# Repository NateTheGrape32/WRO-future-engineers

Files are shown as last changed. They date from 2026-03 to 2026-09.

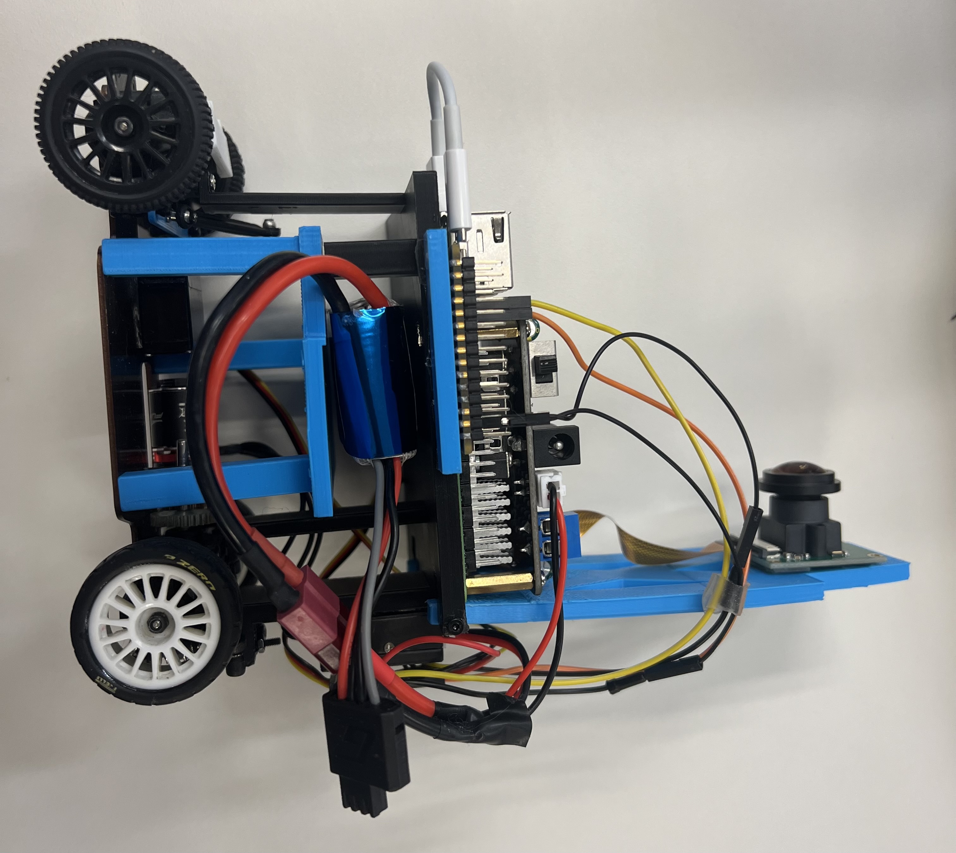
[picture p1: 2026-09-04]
CarPhoto/IMG_4004.jpeg

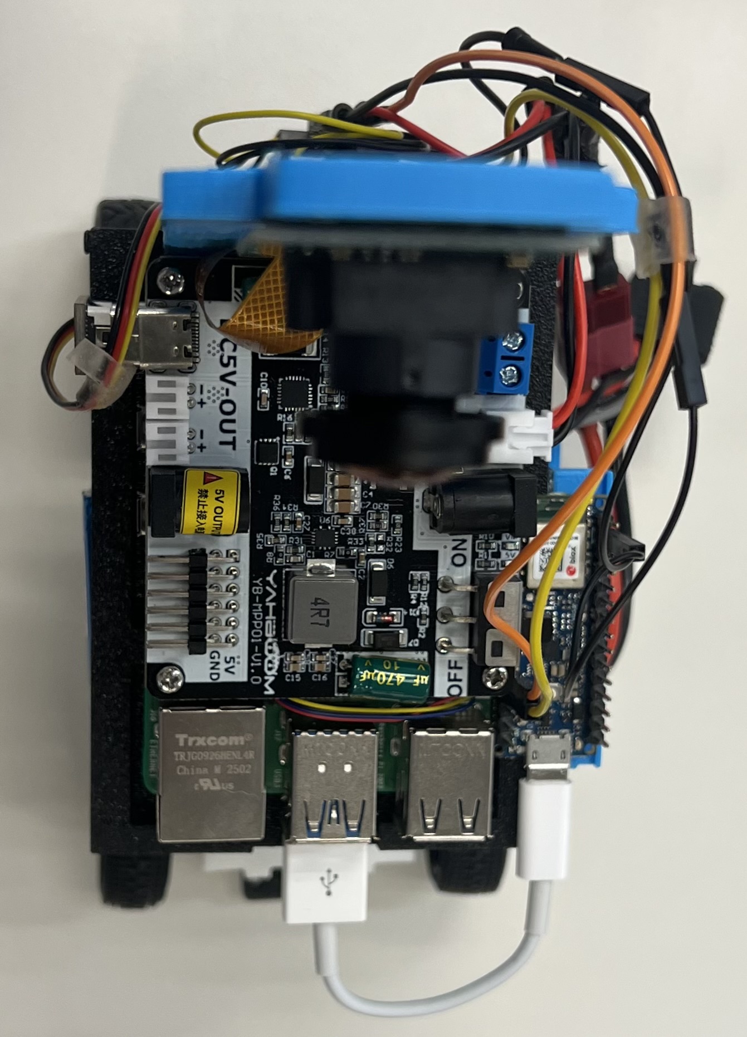
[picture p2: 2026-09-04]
CarPhoto/IMG_4001.jpeg

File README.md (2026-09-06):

# WRO-future-engineers
WRO 2026 Andrew and Nathan

YouTube Video: 
* [Open Challenge](https://youtu.be/nm6dfaRhhao) 
* [Obstacle Challenge](https://youtu.be/E2D7EVUFy_I)
## Nathan


## Andrew


# Materials
Originally we planned to use the following RC car for its chassis: [Original Chassis](https://www.amazon.ca/Full-Scale-Rear-Wheel-Rechargeable-Control-Crawler/dp/B0G24MWNGD?th=1)

However, this did not have the things that we wanted so we switched chassis to this one: [New Chassis](https://www.aliexpress.com/item/1005007171270606.html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)

In addition, we used this 2D LiDAR: [2D Lidar](https://www.aliexpress.com/item/1005003012681021.html?spm=a2g0o.order_list.order_list_main.31.67dd18029q37Y0)

This Pi camera: [Pi Camera](https://www.aliexpress.com/item/1005009258177201.htmlpdp_npi=6%40dis%21USD%21%2430.99%21%2415.19%21%21%21%21%21%402101e83017699792506122817ed50e%2112000048516190389%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) 

This Pi Power Regulator: [Power Regulator](https://ca.robotshop.com/products/yahboom-power-supply-expansion-board-raspberry-pi-5) 

This Battery/Power Supply: https://genstattu.com/gens-ace-1300mah-2s-7-4v-45c-g-tech-lipo-battery-pack-with-deans-plug/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 

This Arduino Nano: [Arduino Nano](https://store-usa.arduino.cc/products/nano-33-ble-sense-rev2) 

This Button: [Button](https://www.amazon.ca/dp/B01J9KO7DC?ref=ppx_yo2ov_dt_b_fed_asin_title&th=1)

Servo motor for driving: [Servo Motor](https://hitecrcd.com/hs-5055mg-economy-metal-gear-feather-servo/) 

# Mobility & Mechanical Design
In creating the chassis, we needed to incorporate these things which was done by:
- low center of gravity to maintain balance and reach higher speeds
    - creating a compact design as close to the ground as possible
    - Only light elements at the very top of the robot(camera)
- front wheel steering to have simple control over robot movement
    - choosing a chassis with Ackerman steering
    - controlling it with a servo motor
- differential gears
    - choosing a chassis with 2WD & differential gears
    - controlling it with a DC motor
- decent steering angle
    - Choosing a chassis that enabled an angle range of 65°–95°, center 80°
    - Programming our code to allow these angles through use of servo motor

Speed choice: MOTOR_DRIVE = 1600 µs
Through use of testing, we concluded that this is the fastest speed in which we could consistently obtain the same results, navigating safely through the challenge. 1500 is its stationary position.

# Gif
azhn33

# Wiring Diagram(file also included above)


# Power and Sensor Architecture
The Battery powers the Raspberry Pi, which is the master controller, through the Raspberry Pi's power regulator. The Raspberry Pi receives information from the Pi Camera. The Raspberry Pi then sends basic commands to the Arduino Nano which sends the information through the ESC into the servo and DC motors, which controls the steering and speed of the robot. 

Battery -> Power Regulator -> Raspberry Pi -> Arduino Nano -> ESC -> Servo & DC Motors

In choosing our sensor, we decided upon the the Pi camera because we deemed it would work well with the Raspberry Pi and had all the necessary functions such as a wide camera view and colour differentiation enabling it to see both the walls and pillars

# Software Architecture & Obstacle Strategy
## Open Challenge
For the Open Challenge, we have 2 modes; TURNING MODE and FOLLOW_WALL MODE. 
### FOLLOW_WALL MODE
During the wall following mode, the robot uses a combination of PD control and the Pi cameras input of the amount of the walls within its view in order to calculate how close to each wall the robot is, adjusting the robot as it goes. It automatically knows that the the bigger wall is closer and should move towards the smaller of the 2. To achieve this, we had 2 ROI(regions of intrest) on each side of the camera in which the camera would detect the amount of black, Thus knowing the ratio of the distance to each. In using this ratio, we could calculate what needed to be done in order to get to the middle. Originally, we set the kp(present error) = 0.5 & kd(predicted future error) = 0.1 but after further testing, we concluded that the robot didn't adjust quickly enough so with testing, we concluded that the perfect numbers were kp = 0.7 & kd = 0.3. 
### TURNING MODE
On the other hand, TURNING MODE is used once one of the walls disappears completely. Once this is the case, we know that the robot has reached a point where there is no wall on one side and so the robot starts turning for a few seconds or until the wall is visible again on the side where it previously wasn't. This allows us to preform the sharper turns without having to increase the kp & kd values to ones that may have the robot overcorrect. 

## Obstacle Challenge
Meanwhile, for the Obstacle Challenge, the Pi camera notifies the pi of the closest pilar, whether red or green. When the pi receives this information, it shifts over to one side of the track by increasing the amount of wall the camera should be seeing on one side compared to the other. 

## Lap Counting
Meanwhile, the robot also counts the laps using the blue and orange lines. after having counted 23 blue and orange lines, the robot enters a time of "STOP_DELAY" in order to stop not at the line located in the corner of the map but at the intended side of the map. 
In the end, all of the motor commands are sent to the Arduino Nano as simple commands, only stating whether it is a command to the servo motor or the DC motor and what degree/speed it should be set to. 

# Systems Thinking & Engineering Decisions

## Arduino ↔ Raspberry Pi Split

We divided the robot's jobs between the Arduino and Raspberry Pi based on what each device is good at:
- Arduino: Handles the IMU and controls the motors using PWM.
- Raspberry Pi: Handles the camera and computer vision using OpenCV.

The Arduino is better for tasks that need very accurate timing. The Raspberry Pi runs Linux, which can interrupt programs, so it cannot guarantee the precise microsecond timing needed for reliable PWM control. On the other hand, the Arduino does not have enough processing power or the software environment needed to run OpenCV effectively.

This split lets each device focus on the job it is best suited for.

## IMU Drift Mitigation

Gyroscopes can slowly become inaccurate over time because of small measurement errors, known as gyro drift.

To reduce this, the robot calibrates the gyro at startup by taking 2,000 samples over about 6 seconds while the robot is not moving. This gives us an estimate of the gyro's normal error, which can then be removed from later measurements.

We also use a dead-zone where values with abs(z) < 0.1 are treated as zero. This stops very small amounts of sensor noise from being interpreted as real movement.

The tradeoff is that extremely small rotations might be ignored. However, this is acceptable because we care more about reliably detecting larger turns than detecting tiny movements.

## Color Space Choices

We use different color spaces for different vision tasks.

- LAB: Used for detecting walls. It handles changes in brightness better, making wall detection more reliable under different lighting.
- HSV: Used for detecting colored pillars and lines. It makes it easier to isolate specific colors based on their hue.

Using different color spaces is a tradeoff: instead of using one method for everything, we chose the method that works best for each type of object.

## Iteration and Improvements

The robot was improved through repeated testing and changes shown in the commit history.

Some important improvements included:
- kp and kd tuning: Adjusted the PID controller to make the robot steer more smoothly and accurately.
- Reduced ROI height: Focused vision processing on the most useful part of the image.
- Added IMU turn confirmation: Used the IMU to help confirm that a turn actually happened instead of relying only on the camera.
- Added pillar detection: Improved the robot's ability to recognize important objects in its environment.

These changes show an implement → test → improve process. Instead of designing everything perfectly from the start, we used testing and observed problems to guide improvements.

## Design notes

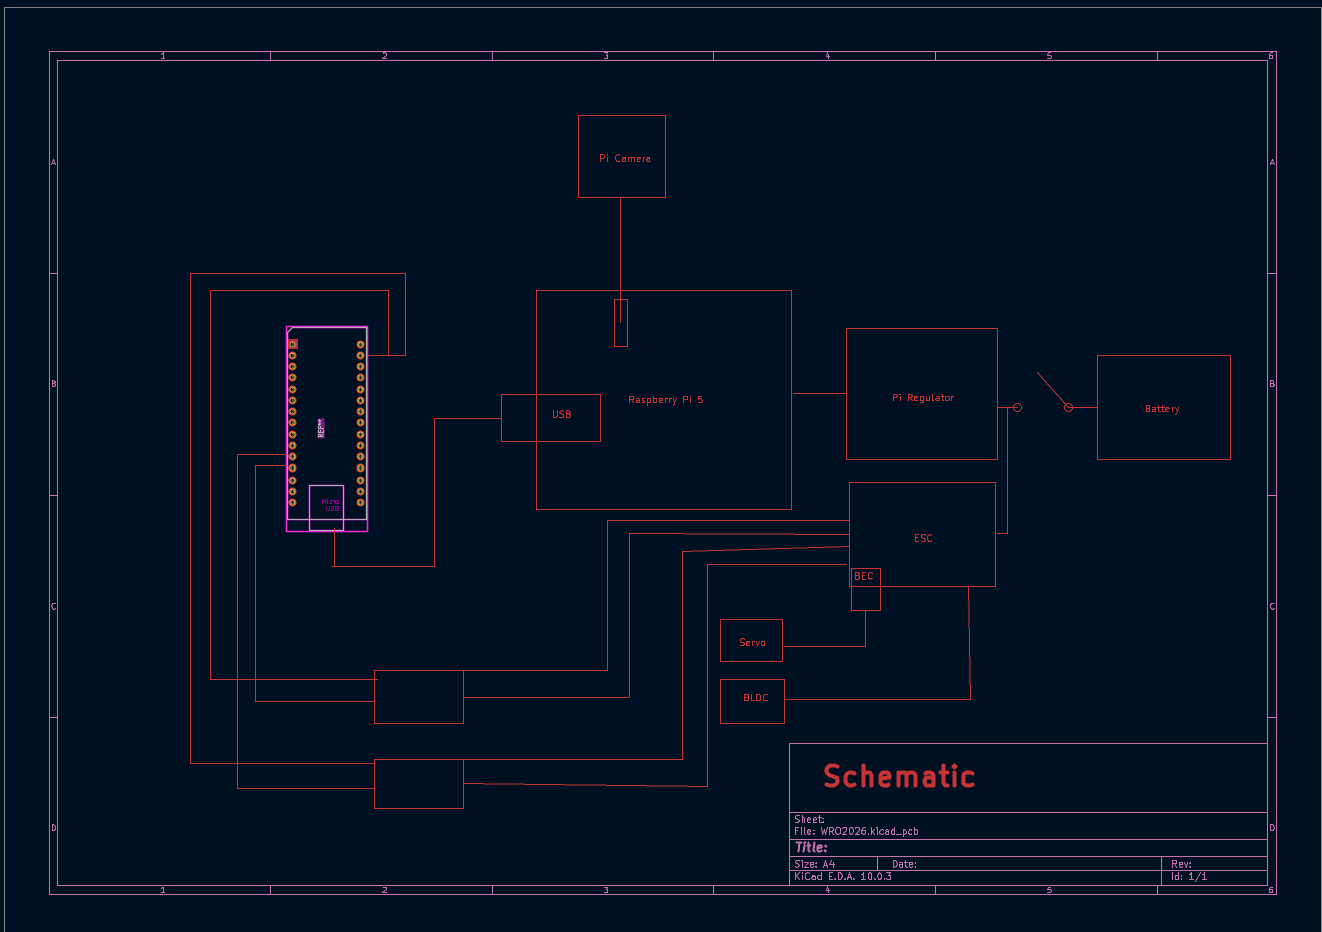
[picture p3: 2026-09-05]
Schematic.png

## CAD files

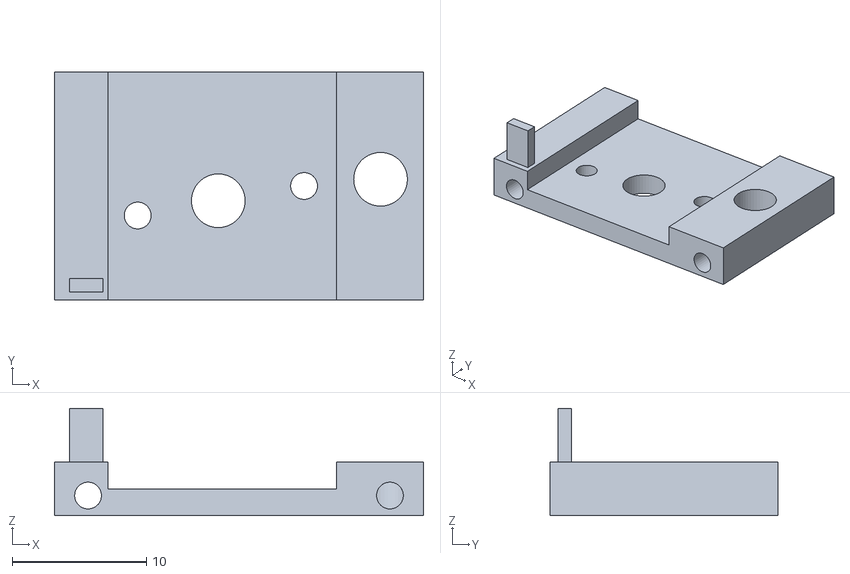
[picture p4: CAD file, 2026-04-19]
3D Designs/GearHolder2.stl
27.5 x 17.0 x 8.00

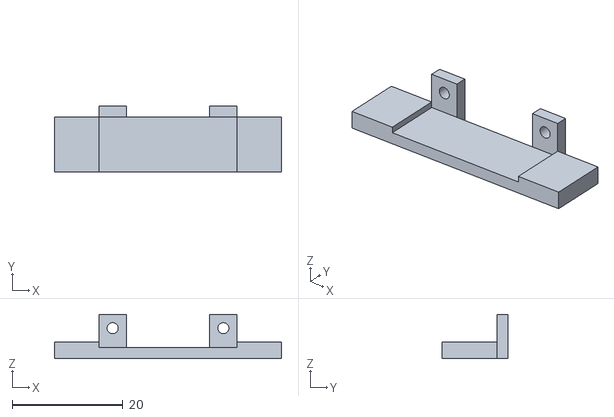
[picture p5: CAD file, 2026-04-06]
3D Designs/Wheel holder2.stl
41.0 x 12.0 x 8.00

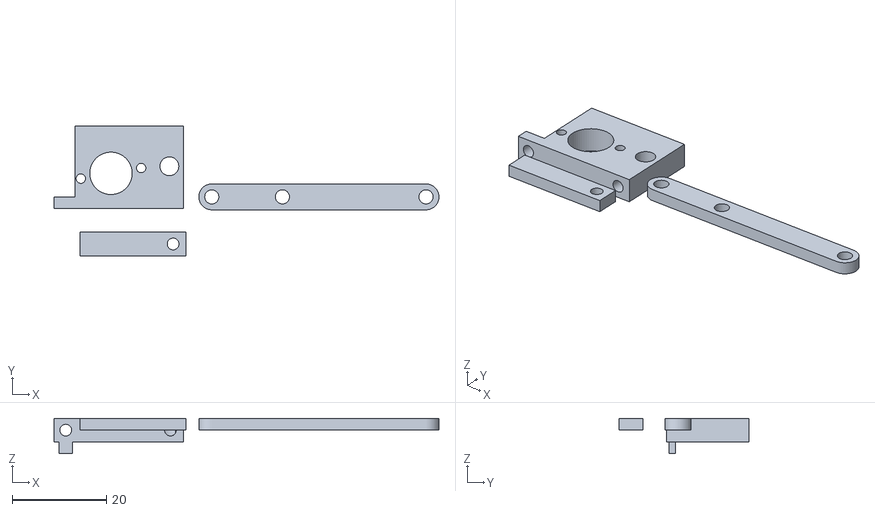
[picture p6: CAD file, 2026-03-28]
3D Designs/Bottom Parts.stl
81.8 x 27.5 x 7.50

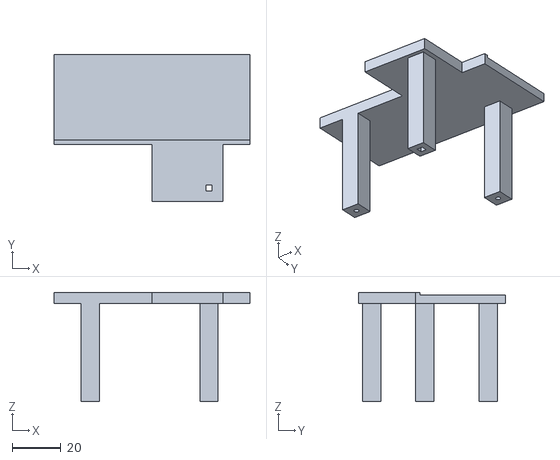
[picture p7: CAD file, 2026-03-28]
3D Designs/Battery & Arduino.stl
80.0 x 60.0 x 44.5

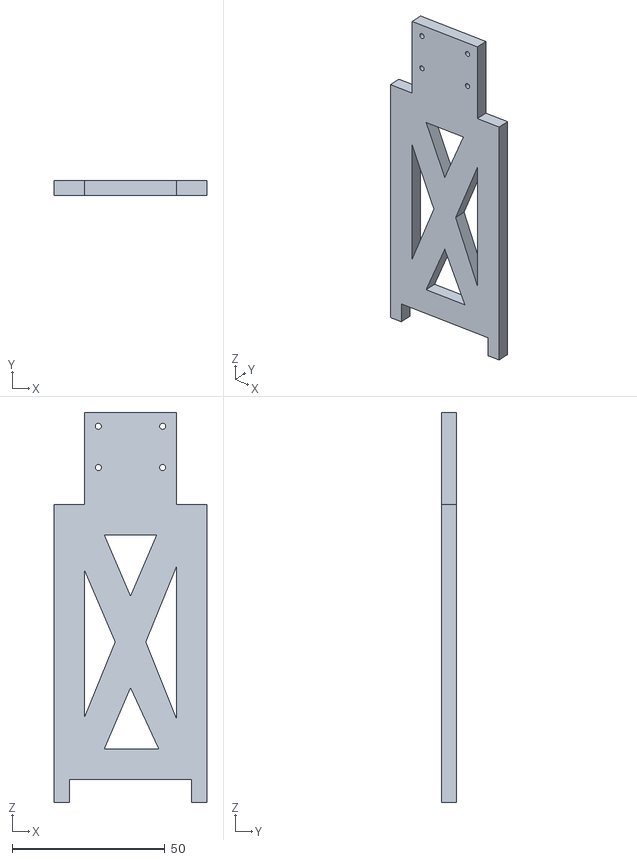
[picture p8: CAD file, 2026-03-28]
3D Designs/Camera.stl
50.0 x 5.00 x 127.5

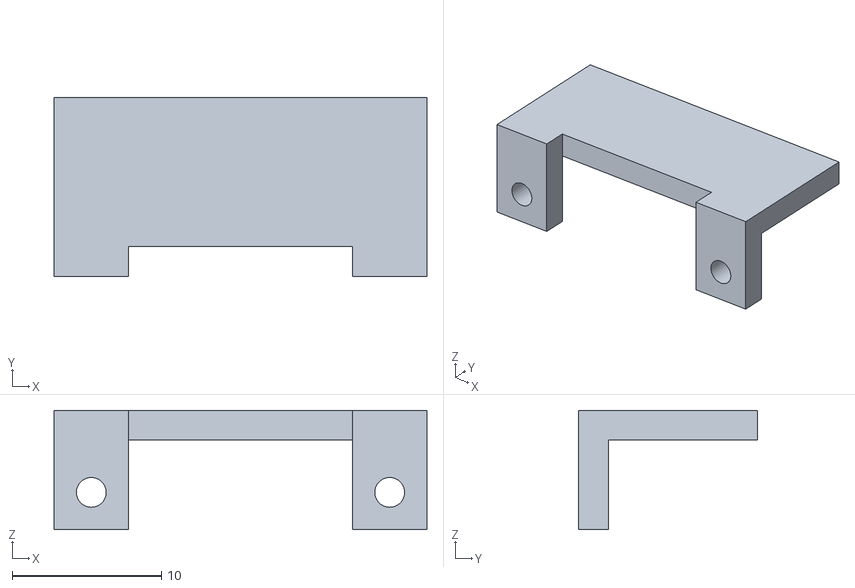
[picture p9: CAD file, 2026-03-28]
3D Designs/Wheel holder.stl
25.0 x 12.0 x 8.00

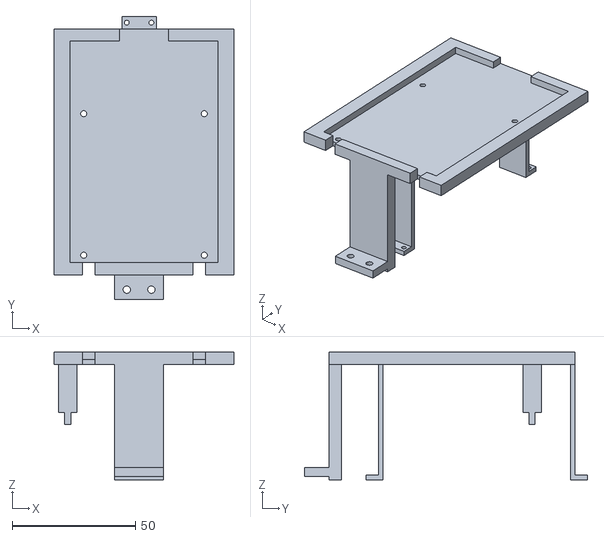
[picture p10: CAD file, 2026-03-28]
3D Designs/raspberryPi.stl
73.0 x 115.0 x 52.0

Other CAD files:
3D Designs/GearHolder.stl

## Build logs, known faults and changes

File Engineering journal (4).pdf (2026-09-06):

Engineering Journal

WRO Autonomous Driving Challenge

Team Name: Potato Nadoes
Country: Canada
Competition Year: 2026
Team Members: Nathan Li and Andrew Deng

YouTube Video(Open Challenge): https://youtu.be/nm6dfaRhhao

YouTube Video(Obstacle Challenge): https://youtu.be/E2D7EVUFy_I

Abstract

Our team developed an autonomous vehicle designed to sense walls and obstacles, adjusting to them. Throughout the project, we followed an iterative engineering process: we identified problems, developed solutions, tested them, analyzed the results, and redesigned the system where necessary. Our final vehicle combines servo motor Ackerman steering, DC motor 2WD with differential gears, Pi camera, and raspberry pi
5. Our proudest engineering achievement was [specific achievement], because it required us to solve [specific technical challenge] through multiple rounds of testing and refinement.
1. The Challenge & Our Systems Strategy

1.1 Understanding the Challenge

Before building the vehicle, we broke the overall autonomous-driving problem into smaller engineering systems:

Mechanical system – chassis, wheels, steering, drivetrain

Power system – battery, voltage regulation, motor power

Sensing system – cameras, encoders, IMU, 2D Lidar

Computing system – onboard computer and microcontrollers

Software system – perception, decision-making, control

Testing system – repeatable experiments, measurements, and performance evaluation

This decomposition allowed us to develop and test individual subsystems before integrating the complete vehicle.

1.2 Constraints

During development, we identified several important constraints:

Constraint | Why it matters | Example engineering impact
Vehicle size: 300 × 200 × 300 mm max | Limits chassis and
| component placement | We had to make the sensor
| | mounts compact.
Vehicle weight: 1.5 kg max Affects acceleration,
| traction, and motor load | We used lighter materials to leave
| | weight for electronics.
4 wheels required | Limits drivetrain
| architecture | We couldn't use a differential-drive
| | layout.
One steering actuator | Limits steering design We needed a mechanically
| | synchronized steering system.
Maximum 2 driving motors Limits available driving
| power | Motor selection and gearing
| | became important.
No omnidirectional/ball
wheels | Limits wheel selection We needed conventional wheels
| | with a suitable steering geometry.
Fully autonomous operationNo human intervention
| during the run | Software needed reliable recovery
| | and decision-making.
No RF/Bluetooth/Wi-Fi during competition | Prevents wireless
| control/communication | Debugging and inter-controller
| | communication had to be wired or
| | disabled.
Sensors are unrestricted | Gives freedom but
| creates integration
| challenges | We had to balance sensor
| | capability against weight, space,
| | processing, and power.

Battery choice is

unrestricted | Lots of design freedom | We still had to balance capacity,
| | weight, voltage, and current
| | capability.
Only wired communication between electromechanical components | Limits communication
| architecture | We had to carefully plan wiring
| | and connectors.

Fixed vehicle size during
the run
| Prevents expanding
| mechanisms from
| simplifying parking | Our final dimensions had to work
| | for both driving and parking.
2. Mechanical Iteration & Mobility

2.1 Chassis Evolution

Rather than designing the final chassis immediately, we developed several versions.

Version 1: Chassis bought from amazon (Feb 22 2026)

Problem: The chassis that we purchased off amazon was not very modification friendly, very difficult to tear apart and did not have differential gears or a usable steering system

Test Result: We were unable to put our servo and DC motors to use and designing 3D prints was very difficult.

Lesson: This taught us that we can't truly be sure of what we're purchasing online as it may seem usable before we actually receive it.

Change for Version 2: We switched to a simple chassis with only the required things such as differential gears and a steering system. (March 1 2026)

Figure 1 – Version 1 prototype(gear system)

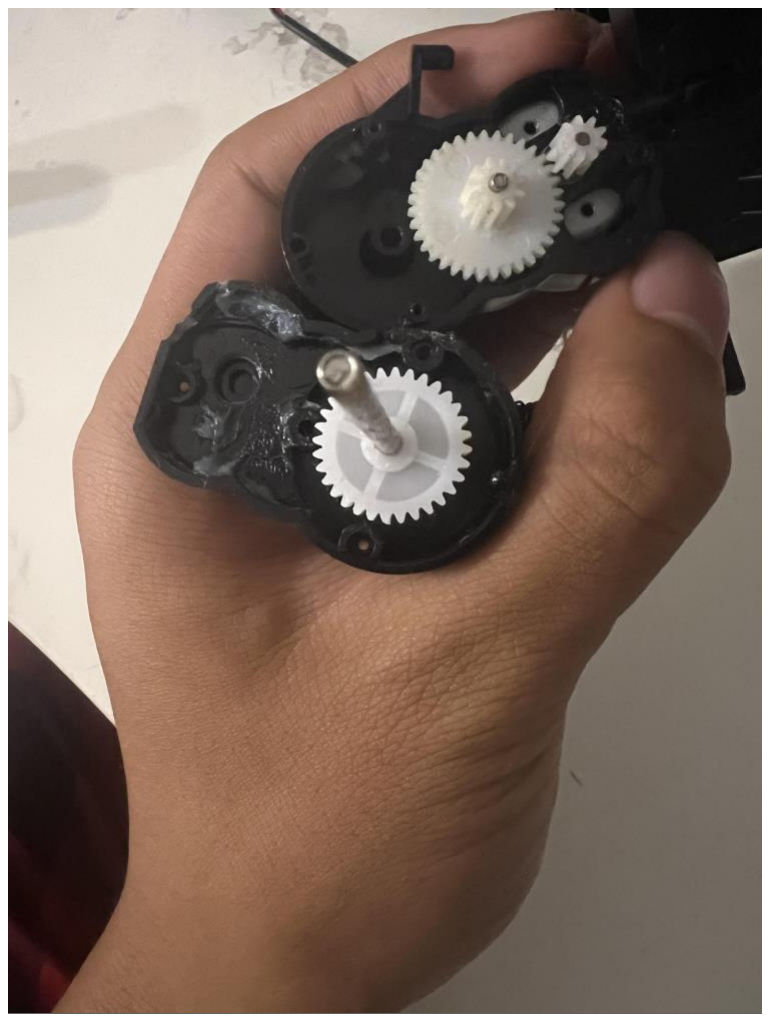
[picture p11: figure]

Version 3:

Problem identified from Version 2: The chassis had nothing to hold down the wheels

Modification: We added a wheel holder over to keep the wheels down using a 3D print

Test Result: It worked for a while but then broke, and we had to create new ones.

Lesson: We learned to always have spare parts in case the 3D prints broke.

Change for Version 3: Gear holder created

Version 3 – Final Design(March 22 2026)

The final chassis incorporated differential gears and a working steering system, completing everything we needed for the competition. These changes were based on the results of previous physical tests rather than solely on assumptions.

Figure 3 – Final chassis

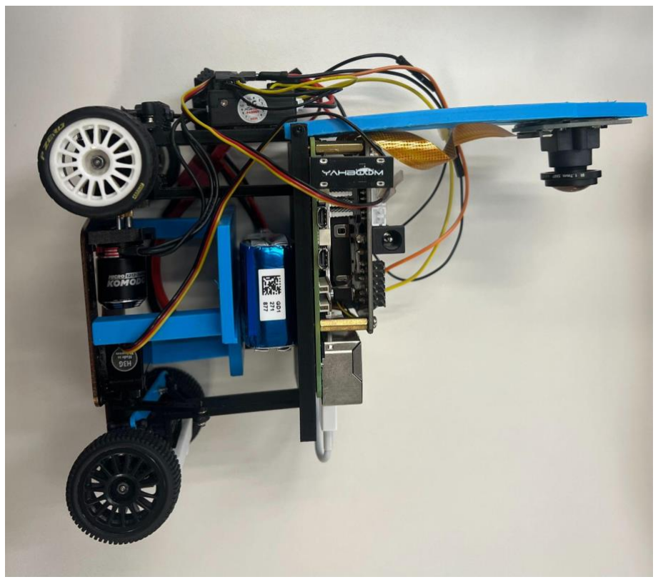
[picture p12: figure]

2.2 Mechanical Testing(June 27 2026)

One significant problem was the steering system.

As time went on, we observed that the robot tended to drift off to one side. We determined that the likely cause was that the gear holder wasn't even. We changed the software and repeated the experiment.

The software change fixed the problem temporarily but reduced our steering angle and made the robot slightly less consistent.

So, we designed a better wheel holder, capable of giving each of the wheels equal grip on the ground

This demonstrated that although some problems are temporarily fixable through software solutions, removing the root is always the best solution.

Although it was slightly disappointing when the first chassis we got didn’t work out, our coaches were extremely supportive, helping us get back on our feet very quickly, encouraging us to quickly be able to continue working on a new chassis at full force. Without them, it would’ve likely taken a much longer time to get started with a new chassis.

3. Power & Sensor

3.1 Power Architecture

Our electrical system consists of Power supply Expansion board for Raspberry Pi 5, Power supply Expansion board for Raspberry Pi 5, HS-5055MG 11.9g Metal Gear Digital Micro Servo, and Pi camera.

Power Budget

Component | Voltag e | Typical Current | Peak Current | Typical Power | Peak Power
Raspberry Pi 5 | 5 V | ~1.2 A | ~2.5 A | ~6 W | ~12.5 W
Power Supply Expansion Board | 5 V | ~0.1 A | ~0.2 A | ~0.5 W | ~1 W
HS-5055MG Servo | 4.8–6
V
~0.2–0.5 A | ~1–1.5 A | ~1–3 W | ~5–9 W
Pi Camera | 5 V | ~0.1–0.2 A | ~0.25 A | ~0.5–1 W | ~1.25 W
DC Motor | 5 V | ~0.5 A | ~1.5 A | ~2.5 W | ~7.5 W
TOTAL | | ~2.1–2.5 A | ~5.45–5.95 A | ~10.5–13 W | ~27–31 W

This is why we needed at least a 5V 6A battery

3.2 Sensor Selection

We selected the Pi camera because it worked well with the raspberry pi 5 that we were using. However, this was not the first Pi Camera we purchased. The first one(Feb 1 2026) didn’t have the correct connector to the Raspberry Pi and so we were forced to switch to another(Feb 22 2026)

3.3 Sensor Placement

Sensor placement was determined through testing rather than convenience.

For example, the Pi camera was positioned close to the top because it was able to see a large part of the map. We discovered that positioning was originally slightly too high and slightly on one side.

Through testing, we found the perfect position for the Pi camera.

4. Software Logic & Problem Solving

4.1 Software Architecture

Our software is divided into several stages:

Perception -> Decision Making (raspberry pi) -> Commands to Slave Controller (Arduino Nano) -> Motor Control

This separation allowed us to modify individual parts of the software without completely rewriting the system.

4.2 State Machine

The vehicle operates using a state-based control system.

Example states include:

Searching → Lane Following → Obstacle Detection → Avoidance → Recovery → Lane Following

Each state has defined inputs, actions, and transition conditions.

4.3 Control Tuning

For steering control, we used PD control, calculating both the Proportional (P) and Derivative (D) Control.

We adjusted both kp and kd while measuring how sharp each turn was and how consistent the robot was with the sharpness.

Though this part of the project was certainly difficult with the software having some problems, constantly shutting off and slowing our progress, we managed to push through, figuring out it was a battery problem and moving forwards with what we had. Something that was essential to our success in the software part was our past experience with the WRO competition, having participated in other categories before. By using our experience from this, we were able to put our code together far easier than someone who has no experience.

5. What We Would Improve

Engineering did not end with the final prototype. If we had additional development time, we would improve:

1. Even more compact

We would make the robot even more compact, having a lower center of gravity so it could be more stable.

2. Attach 2D Lidar

We would add a space for a 2D Lidar because it could help us complete tasks such as the parallel parking.

3. Better Camera Placement

We would change the camera placement to get a better view of the field.

The most important next improvement would be to change the camera placement. Often when testing, it was a small problem that we were unable to see far enough to each side close to the robot. In the end, it worked out alright, however if we had the time to redesign the robot, the camera would’ve likely found itself slightly higher with a tilt downwards.

Although it was slightly unfortunate that we were unable to make these changes, we were able to learn a lot about the importance of planning and truly thinking everything through before creating the robot you’ll be working with for the next few months.

6. Engineering Lessons

The most important lessons from this project were:

Test before assuming.
Models and theoretical calculations helped us predict performance, but physical testing frequently revealed unexpected behavior.

Measure instead of guessing.
We improved our designs when we replaced subjective observations with measurements and repeatable tests.

Subsystems are interconnected.
A mechanical change could affect sensors, power consumption, software behavior, or vehicle stability.

Failure is useful engineering data.
Our most valuable improvements often came from failures because they revealed weaknesses that were not obvious during initial design.

Iteration produced our final vehicle.
The final design was not the result of one perfect idea. It was the result of repeated cycles of designing, building, testing, analyzing, and improving.

This competition was certainly a challenge with no shortcuts. It required a large amount of time and effort that were sometimes not present everyday and staying motivated, especially with a number of setbacks, was definitely challenging. In addition, balancing the task with our own schedules was taxing, trying to complete small bits between work or activities. One thing that motivated me to keep going through all of this was the people around me who kept making progress. In order to not be left so far behind, there was no choice but to keep moving forwards. It was a difficult 7-8 months but in the end, effort never lets you down. Your starting point isn’t what matters, it's what you do with where you’ve been placed, doing your best to have the best finish possible.

Appendix – Evidence Index

The Engineering Journal explains the engineering process, while our GitHub repository contains the detailed technical assets.

GitHub Repository

GitHub Repository: (https://github.com/NateTheGrape32/WRO-future-engineers/tree/main) NateTheGrape32/WRO-future-engineers: WRO 2026 Andrew and Nathan (https://github.com/NateTheGrape32/WRO-future-engineers/tree/main)

Contains:

Source code

Wiring diagrams

Vehicle photographs

Team photographs

Build instructions

Detailed README

Additional technical documentation

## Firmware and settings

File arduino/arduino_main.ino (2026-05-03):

#include <Arduino.h>
#include <ctype.h>
#include <string.h>
#include <stdlib.h>
#include <Servo.h>
#include <Arduino_BMI270_BMM150.h>

static float q0=1, q1=0, q2=0, q3=0;
static float eIx=0, eIy=0, eIz=0;
static unsigned long lastTime = 0;
static float gbx=0, gby=0, gbz=0;

// reference quaternion everything is relative to this after zeroing
static float r0=1, r1=0, r2=0, r3=0;

// cached mag updated only when new data arrives, used every frame
static float cachedMx=0, cachedMy=0, cachedMz=0;

static const size_t MAX_LINE = 16;  // Max command line length, excluding EOL
static char lineBuf[MAX_LINE + 1];
static size_t lineLen = 0;
static const char SOC = '$';  // start of command character
static bool inCommand = false;
static float biasX = 0.0, biasY = 0.0, biasZ = 0.0;
Servo servo;
Servo motor;
#define SERVO_PIN 9
#define MOTOR_PIN 8

#define DECLINATION_DEG  -10.1f

// This need to be calibrated board to board. Please uncomment calibrateMag() under void loop to do so.
#define MAG_X_OFFSET  39.0f
#define MAG_Y_OFFSET  30.0f
#define MAG_Z_OFFSET  13.5f

// Kp = how fast it corrects, Ki = slowly kills gyro bias
#define Kp  2.0f
#define Ki  0.05f

void calibrateGyro() {
  Serial.println("Keep still — calibrating gyro...");
  float sx=0, sy=0, sz=0;
  int n = 2000;
  for (int i=0; i<n; i++) {
    float gx,gy,gz;
    while (!IMU.gyroscopeAvailable());
    IMU.readGyroscope(gx,gy,gz);
    sx+=gx; sy+=gy; sz+=gz;
    delay(3);
  }
  gbx=sx/n; gby=sy/n; gbz=sz/n;
  Serial.print("Gyro bias: ");
  Serial.print(gbx,4); Serial.print(" ");
  Serial.print(gby,4); Serial.print(" ");
  Serial.println(gbz,4);
}

// run once, rotate board in all directions 30s, paste offsets above
void calibrateMag() {
  Serial.println("Rotate board in all directions for 30s...");
  float xmin=1e9,xmax=-1e9,ymin=1e9,ymax=-1e9,zmin=1e9,zmax=-1e9;
  unsigned long start = millis();
  while (millis()-start < 30000) {
    if (!IMU.magneticFieldAvailable()) continue;
    float mx,my,mz;
    IMU.readMagneticField(mx,my,mz);
    xmin=min(xmin,mx); xmax=max(xmax,mx);
    ymin=min(ymin,my); ymax=max(ymax,my);
    zmin=min(zmin,mz); zmax=max(zmax,mz);
    delay(10);
  }
  Serial.println("Done! Paste these into your #defines:");
  Serial.print("#define MAG_X_OFFSET  "); Serial.println((xmin+xmax)/2, 4);
  Serial.print("#define MAG_Y_OFFSET  "); Serial.println((ymin+ymax)/2, 4);
  Serial.print("#define MAG_Z_OFFSET  "); Serial.println((zmin+zmax)/2, 4);
  while(1);
}

void mahonyUpdate(float ax, float ay, float az,
                  float gx, float gy, float gz,
                  float mx, float my, float mz, float dt) {
  float norm;

  norm = sqrtf(ax*ax+ay*ay+az*az);
  if (norm == 0) return;
  ax/=norm; ay/=norm; az/=norm;

  norm = sqrtf(mx*mx+my*my+mz*mz);
  if (norm == 0) return;
  mx/=norm; my/=norm; mz/=norm;

  float hx = 2*(mx*(0.5f-q2*q2-q3*q3) + my*(q1*q2-q0*q3) + mz*(q1*q3+q0*q2));
  float hy = 2*(mx*(q1*q2+q0*q3) + my*(0.5f-q1*q1-q3*q3) + mz*(q2*q3-q0*q1));
  float bx = sqrtf(hx*hx+hy*hy);
  float bz = 2*(mx*(q1*q3-q0*q2) + my*(q2*q3+q0*q1) + mz*(0.5f-q1*q1-q2*q2));

  float vx = 2*(q1*q3-q0*q2);
  float vy = 2*(q0*q1+q2*q3);
  float vz = q0*q0-q1*q1-q2*q2+q3*q3;
  float wx = 2*(bx*(0.5f-q2*q2-q3*q3) + bz*(q1*q3-q0*q2));
  float wy = 2*(bx*(q1*q2-q0*q3)       + bz*(q0*q1+q2*q3));
  float wz = 2*(bx*(q0*q2+q1*q3)       + bz*(0.5f-q1*q1-q2*q2));

  float ex = (ay*vz-az*vy) + (my*wz-mz*wy);
  float ey = (az*vx-ax*vz) + (mz*wx-mx*wz);
  float ez = (ax*vy-ay*vx) + (mx*wy-my*wx);

  eIx += Ki*ex*dt;
  eIy += Ki*ey*dt;
  eIz += Ki*ez*dt;

  gx += Kp*ex + eIx;
  gy += Kp*ey + eIy;
  gz += Kp*ez + eIz;

  gx *= DEG_TO_RAD;
  gy *= DEG_TO_RAD;
  gz *= DEG_TO_RAD;

  float dq0 = 0.5f*(-q1*gx-q2*gy-q3*gz)*dt;
  float dq1 = 0.5f*( q0*gx+q2*gz-q3*gy)*dt;
  float dq2 = 0.5f*( q0*gy-q1*gz+q3*gx)*dt;
  float dq3 = 0.5f*( q0*gz+q1*gy-q2*gx)*dt;

  q0+=dq0; q1+=dq1; q2+=dq2; q3+=dq3;

  norm = sqrtf(q0*q0+q1*q1+q2*q2+q3*q3);
  q0/=norm; q1/=norm; q2/=norm; q3/=norm;
}

void readAndFuse(float dt) {
  // update mag cache only when fresh data is ready (it's slow ~10Hz)
  if (IMU.magneticFieldAvailable()) {
    float mx,my,mz;
    IMU.readMagneticField(mx,my,mz);
    // BMI270 rotated 90deg on board + align to same frame
    cachedMx =  my - MAG_X_OFFSET;
    cachedMy = -mx - MAG_Y_OFFSET;
    cachedMz = -mz - MAG_Z_OFFSET;
  }

  // always run filter at full speed with last known mag
  if (!IMU.accelerationAvailable() || !IMU.gyroscopeAvailable()) return;

  float ax,ay,az,gx,gy,gz;
  IMU.readAcceleration(ax,ay,az);
  IMU.readGyroscope(gx,gy,gz);
  gx -= gbx; gy -= gby; gz -= gbz;

  float rax=-ax, ray=ay, raz=az;
  float rgx=-gx, rgy=gy, rgz=gz;

  mahonyUpdate(rax,ray,raz, rgx,rgy,rgz, cachedMx,cachedMy,cachedMz, dt);
}

void warmupAndZero() {
  Serial.println("Warming up — keep still...");

  // seed the mag cache before warmup starts
  while (!IMU.magneticFieldAvailable());
  float mx,my,mz;
  IMU.readMagneticField(mx,my,mz);
  cachedMx =  my - MAG_X_OFFSET;
  cachedMy = -mx - MAG_Y_OFFSET;
  cachedMz = -mz - MAG_Z_OFFSET;

  unsigned long start = millis();
  lastTime = micros();
  while (millis()-start < 3000) {
    unsigned long now = micros();
    float dt = (now-lastTime)*1e-6f;
    if (dt < 0.002f) continue;
    lastTime = now;
    if (dt > 0.05f) dt = 0.05f;
    readAndFuse(dt);
  }

  // store inverse of settled quaternion so all angles are relative to startup pose
  r0= q0; r1=-q1; r2=-q2; r3=-q3;
  Serial.println("Zeroed. Go!");
}

static void processCommand(char* cmd) {
  if (!cmd || cmd[0] == '\0') return;

  char* cr = strchr(cmd, '\r');
  if (cr) *cr = '\0';

  while (*cmd && isspace((unsigned char)*cmd)) cmd++;  // Trim leading whitespace
  if (*cmd == '\0') return;

  char type = *cmd++;

  // Parse int argument
  char* endp = nullptr;
  long val = strtol(cmd, &endp, 10);

  switch (type) {
    case 'S':                            // Set servo position
      if (val < 0 || val > 180) return;  // Invalid angle
      servo.write(val);
      break;
    case 'M':  // return IMU data and turn
      if (val < 1000 || val > 2000) return;  // Invalid speed
      motor.writeMicroseconds(val);
      break;
    case 'I':
      unsigned long now = micros();
      float dt = (now-lastTime)*1e-6f;
      if (dt < 0.002f) return;
      lastTime = now;
      if (dt > 0.05f) dt = 0.05f;

      readAndFuse(dt);

      // rotate by reference quaternion so output is relative to startup pose
      float rq0 = r0*q0 - r1*q1 - r2*q2 - r3*q3;
      float rq1 = r0*q1 + r1*q0 + r2*q3 - r3*q2;
      float rq2 = r0*q2 - r1*q3 + r2*q0 + r3*q1;
      float rq3 = r0*q3 + r1*q2 - r2*q1 + r3*q0;

      float roll    = atan2f(2*(rq0*rq1+rq2*rq3), 1-2*(rq1*rq1+rq2*rq2)) * RAD_TO_DEG;
      float pitch   = asinf (constrain(2*(rq0*rq2-rq3*rq1), -1.0f, 1.0f)) * RAD_TO_DEG;
      float heading = atan2f(2*(rq0*rq3+rq1*rq2), 1-2*(rq2*rq2+rq3*rq3)) * RAD_TO_DEG;

      // Y axis = forward
      heading += DECLINATION_DEG - 90.0f;
      if (heading < 0)   heading += 360.0f;
      if (heading > 360) heading -= 360.0f;
      Serial.println(heading + 90.0f, 4)
      break;
    default:
      // Ignore unknown command type
      break;
  }
}

void setup() {
  servo.attach(SERVO_PIN, 900, 2100);
  motor.attach(MOTOR_PIN, 1000, 2000);
  servo.write(90);
  motor.writeMicroseconds(1500);

  Serial.begin(115200);
  while (!Serial);

  if (!IMU.begin()) {
    Serial.println("Failed to initialize IMU!");
    while (1);
  }
  Serial.println("IMU initialized successfully.");

  // uncomment once to get mag offsets, paste above, then comment out again
  calibrateMag();

  calibrateGyro();
  warmupAndZero();
  lastTime = micros();
}

void loop() {
  // CMD Processing
  while (Serial.available() > 0) {
    char c = (char)Serial.read();
    if (c == SOC) {
      inCommand = true;
      lineLen = 0;
      continue;
    }
    if (inCommand) {
      if (c == '\n') {
        lineBuf[lineLen] = '\0';  // Null-terminate command
        processCommand(lineBuf);
        inCommand = false;
        lineLen = 0;
        continue;
      }

      if (lineLen < MAX_LINE) {
        lineBuf[lineLen++] = c;  // Append char to command buffer
      } else {
        // Command too long
        inCommand = false;
        lineLen = 0;
      }
    }
  }
}

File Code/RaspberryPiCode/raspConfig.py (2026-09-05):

import cv2
import serial
import traceback
import time
from time import sleep
from picamera2 import Picamera2
import numpy as np

SERIAL_PORT = "/dev/ttyACM0"
BAUD = 115200

SERVO_CENTER = 80
SERVO_LEFT = 65
SERVO_RIGHT = 95
SERVO_RANGE = 85

MOTOR_STOP = 1500
MOTOR_DRIVE = 1600

LEDB = 22
LEDR = 23
LEDG = 24

ROI_LEFT = [30, 280, 180, 610]
ROI_RIGHT = [490, 280, 640, 610]
ROI_CENTER = [180, 375, 490, 415]
ROI_PILLARS = [0, 200, 640, 480]

LAB_LOWER = np.array([0, 0, 0], dtype=np.uint8)
LAB_UPPER = np.array([65, 255, 255], dtype=np.uint8)

HSV_RED_LOWER1 = np.array([0, 90, 90])
HSV_RED_UPPER1 = np.array([7, 255, 255])
HSV_RED_LOWER2 = np.array([171, 80, 80])
HSV_RED_UPPER2 = np.array([179, 255, 255])

HSV_GREEN_LOWER = np.array([40, 100, 0])
HSV_GREEN_UPPER = np.array([85, 255, 255])

PILLAR_THRESH = 100

ENTER_TURN_THRESH_LOWER = 300
ENTER_TURN_THRESH_UPPER = 20000
EXIT_TURN_THRESH = 4000

CONFIRM_FRAMES = 5
EXIT_TIME_THRESH = 0.75
EXIT_ANGLE_THRESH = 80

FOLLOW_TIME_THRESH = 3

BLUE_LOWER = np.array([95,80,80])
BLUE_UPPER = np.array([130,255,255])

ORANGE_LOWER = np.array([5,100,100])
ORANGE_UPPER = np.array([25,255,255])

LINE_THRESH = 1000
STOP_DELAY = 2.0

prevError = 0
mode = "FOLLOW_WALL"
turnSide = None
confirmCount = 0
turnEnterTime = None
turnsCompleted = 0
enterHeading = 0
currentHeading = 0
passedAngle = False

followEnterTime = 0
useIMU = False

mainPillar = None
mainColor = None

lineCount = 0
linePresent = False
goClockwise = False

stopScheduled = False
stopTime = None

roiArea = (ROI_LEFT[2] - ROI_LEFT[0]) * (ROI_LEFT[3] - ROI_LEFT[1])

ser = serial.Serial(SERIAL_PORT, BAUD, timeout=1)

def clamp(value, low=25, high=130):
    return max(low, min(high, value))

def send_servo(angle):
    angle = int(clamp(angle))
    ser.write(f"$S{angle}\n".encode())

def send_motor(speed):
    ser.write(f"$M{int(speed)}\n".encode())
    
def activate_led(led):
	ser.write(f"$L{led}\n".encode())

def grab_heading():
    ser.reset_input_buffer()
    sleep(0.1)
    ser.write("$I\n".encode())
    while True:
        if ser.in_waiting > 0:
            heading = float(ser.readline().decode().strip())
            break
    return heading

def draw_roi(img, roi, label = ""):
    x1, y1, x2, y2 = roi
    cv2.rectangle(img, (x1, y1), (x2, y2), (0, 255, 0), 2)

    if label:
        cv2.putText(
            img,
            label,
            (x1, y1 - 10),
            cv2.FONT_HERSHEY_SIMPLEX,
            0.7,
            (0, 255, 0),
            2
        )


def find_wall_area(frame, roi):
    x1, y1, x2, y2 = roi


    roiImg = frame[y1:y2, x1:x2]

    lab = cv2.cvtColor(roiImg, cv2.COLOR_RGB2Lab)
    lab = cv2.GaussianBlur(lab, (7, 7), 0)

    mask = cv2.inRange(lab, LAB_LOWER, LAB_UPPER)
    _, maskRed, __ = detect_pillars(frame, roi, HSV_RED_LOWER1, HSV_RED_UPPER1, HSV_RED_LOWER2, HSV_RED_UPPER2)
    _, maskGreen, __ = detect_pillars(frame, roi, HSV_GREEN_LOWER, HSV_GREEN_UPPER)
    
    mask = cv2.bitwise_xor(mask, maskRed)
    mask = cv2.bitwise_xor(mask, maskGreen)

    kernel = np.ones((5, 5), np.uint8)

    mask = cv2.morphologyEx(mask, cv2.MORPH_OPEN, kernel, iterations=1)
    mask = cv2.morphologyEx(mask, cv2.MORPH_CLOSE, kernel, iterations=2)

    contours, _ = cv2.findContours(
        mask,
        cv2.RETR_EXTERNAL,
        cv2.CHAIN_APPROX_SIMPLE
    )

    largest = None
    largestArea = 0

    for c in contours:
        area = cv2.contourArea(c)

        if area > largestArea:
            largestArea = area
            largest = c

    if largest is not None:
        largest += np.array([x1, y1])

    return largest, mask, largestArea

def detect_colored_line(frame):

    x1, y1, x2, y2 = ROI_CENTER

    roi = frame[y1:y2, x1:x2]

    hsv = cv2.cvtColor(roi, cv2.COLOR_RGB2HSV)

    blueMask = cv2.inRange(
        hsv,
        BLUE_LOWER,
        BLUE_UPPER
    )

    orangeMask = cv2.inRange(
        hsv,
        ORANGE_LOWER,
        ORANGE_UPPER
    )

    kernel = np.ones((3,3), np.uint8)

    blueMask = cv2.morphologyEx(
        blueMask,
        cv2.MORPH_OPEN,
        kernel
    )
    
    orangeMask = cv2.morphologyEx(
		orangeMask,
		cv2.MORPH_OPEN,
		kernel
    )
    
    mask = cv2.bitwise_or(blueMask, orangeMask)


    areaBlue = cv2.countNonZero(blueMask)
    areaOrange = cv2.countNonZero(orangeMask)


    detected = areaBlue > LINE_THRESH or areaOrange > LINE_THRESH
    
    clockwise = True if areaOrange else False

    return detected, mask, clockwise
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

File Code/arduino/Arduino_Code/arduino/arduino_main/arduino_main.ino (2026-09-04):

#include <Arduino.h>
#include <ctype.h>
#include <stdlib.h>
#include <string.h>
#include <Servo.h>
#include <Arduino_BMI270_BMM150.h>

#define SERVO_PIN 9
#define MOTOR_PIN 8

#define MAX_LINE 16
#define START_CHAR '$'

Servo servo;
Servo motor;

char command[MAX_LINE + 1];
int commandLength = 0;
bool readingCommand = false;

float gyroBiasZ = 0;
float heading = 0;
unsigned long lastTime = 0;

//gyro
void calibrateGyro() {
  Serial.println("Keep still — calibrating gyro...");

  float sumZ = 0;
  const int samples = 2000;

  for (int i = 0; i < samples; i++) {
    float x, y, z;

    while (!IMU.gyroscopeAvailable());

    IMU.readGyroscope(x, y, z);
    sumZ += z;

    delay(3);
  }

  gyroBiasZ = sumZ / samples;

  Serial.print("Gyro Z bias: ");
  Serial.println(gyroBiasZ, 4);
}


void startupCalibration() {
  calibrateGyro();

  heading = 0.0f;
  lastTime = micros();

  Serial.println("Ready!");
}


//commands
void processCommand(char *cmd) {
  if (cmd == nullptr || cmd[0] == '\0')
    return;

  // Remove carriage return if there is one
  char *cr = strchr(cmd, '\r');
  if (cr)
    *cr = '\0';

  // Skip spaces
  while (*cmd && isspace(*cmd))
    cmd++;

  if (*cmd == '\0')
    return;

  char type = *cmd++;

  char* endp = nullptr;
  long value = strtol(cmd, &endp, 10);

  switch (type) {

    case 'C':   // Calibrate
      startupCalibration();
      break;

    case 'S':   // Servo
      if (value >= 25 && value <= 130)
        servo.write(value);
      break;

    case 'M':   // Motor
      if (value >= 1000 && value <= 2000)
        motor.writeMicroseconds(value);
      break;

    case 'L':   // LED
      if (value >= 22 && value <= 24) {
        digitalWrite(LEDG, LOW);
        digitalWrite(LEDR, LOW);
        digitalWrite(LEDB, LOW);

        digitalWrite(value, HIGH);
      }
      break;

    case 'I':   // Print heading
      Serial.println(heading);
      break;
  }
}


//setup

void setup() {
  // LEDs
  pinMode(22, OUTPUT);
  pinMode(23, OUTPUT);
  pinMode(24, OUTPUT);

  digitalWrite(22, LOW);
  digitalWrite(23, LOW);
  digitalWrite(24, LOW);

  // Servo and motor
  servo.attach(SERVO_PIN, 900, 2100);
  motor.attach(MOTOR_PIN, 1000, 2000);

  servo.write(80);
  motor.writeMicroseconds(1500);

  // Serial
  Serial.begin(115200);
  while (!Serial);

  // IMU
  if (!IMU.begin()) {
    Serial.println("Failed to initialize IMU!");
    while (true);
  }

  Serial.println("IMU initialized successfully.");
  startupCalibration();
}


//loop
void loop() {

  // Read serial commands
  if (Serial.available()) {
    char c = Serial.read();

    if (c == START_CHAR) {
      readingCommand = true;
      commandLength = 0;
    }
    else if (readingCommand) {

      if (c == '\n') {
        command[commandLength] = '\0';

        processCommand(command);

        readingCommand = false;
        commandLength = 0;
      }

      else if (commandLength < MAX_LINE) {
        command[commandLength++] = c;
      }

      else {
        // Command was too long
        readingCommand = false;
        commandLength = 0;
      }
    }
  }


  // Read gyro
  if (IMU.gyroscopeAvailable()) {

    float x, y, z;
    IMU.readGyroscope(x, y, z);

    z -= gyroBiasZ;

    // Ignore small gyro noise
    if (abs(z) < 0.1)
      z = 0;

    unsigned long now = micros();

    float dt = (now - lastTime) * 0.000001f;

    lastTime = now;

    // Integrate angular velocity into heading
    heading -= z * dt;
  }
}

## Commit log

2026-02-08 Begin working on arduino cmd reciever (2/7/2026)
2026-02-10 Rudimentary command protocol between Arduino and Raspberry Pi for servo and turning V1 complete.
    TODO: gyroscope callibration (2/9/2026)
2026-02-11 Fixed Arduino's ability to read turning commands and parse integer command values. (2/10/2026)
    [arduino.ino]
2026-03-01 Rough List of Materials
    Added the starting pieces we purchased
2026-03-06 start to initiate arduino pins
2026-03-15 created small test for servo functionality
2026-03-15 added servo_tests to its own folder to resolve issue where the file could not run and stated it needed its own folder
    [servo_test.ino]
2026-03-17 Solved servo_test bugs and created file to begin creating a test for the bldc motor.
    [arduino.ino, bldc_test.ino, servo_test.ino]
2026-03-18 Added a test for the bldc motor
2026-03-22 New RaspberryPi platform design
    [raspberryPi.stl]
2026-03-28 Bugfixes for the servo and bldc motor tests:
    1. Fixed ranges and syntax errors
    2. Added ESC arming sequence for bldc_test.ino
    [bldc_test.ino, servo_test.ino]
2026-04-02 Correction to arduino code to control BLDC via PWM
    [arduino_main.ino]
2026-04-02 Adjusted Raspberry Pi's main code to be compatible with the Arduino's code.
2026-04-06 Update designs overview
    added the pieces "Steering" and "Motor Holder" to it
2026-04-06 Update designs overview
    Added wheel holder 2 which does the job much better
2026-04-06 improved the wheel holder
    changed it to better fit the robot
    [Wheel holder2.stl]
2026-04-12 GearHolder uploaded
    improved the gear holder
    [GearHolder.stl]
2026-04-19 Raspi hotfix and additional state
    Updated serial communication settings and refactored the main loop for better control flow and error handling.
    Added an "END" state to initiate a finishing procedure.
    Updated pdController related programming to normalize values.
2026-04-19 Refactor command processing and remove driveStraight
    Removed the driveStraight function and updated command processing for servo and motor control.
    Included additional commands to return data to the Raspberry Pi.
2026-04-19 Change servo control method to write()
    Updated servo control to use write() instead of writeMicroseconds().
2026-04-19 Enhance wall-following logic with sensor feedback
    Reprogrammed FOLLOW_WALL logic to include sensory feedback from the Arduino and to return a fully corrected angle.
    Refactored pdController() to return a value in degrees as correction.
2026-04-19 Update designs overview
    added the second version of gear holder
2026-04-19 Added the newer version of gear holder
    [GearHolder2.stl]
2026-04-26 Bugfix
    - Corrected formatting for Raspberry Pi commands and PD Controller
    - Fixed Arduino command reading
    - Removed the D command
    [arduino_main.ino]
2026-05-03 Added more robust code and calibration for the Arduino's IMU
2026-05-10 Adjusted arduino_main so the code does not permit the servo to turn beyond the physical limits of the chassis.
    Temporarily commented out all code related to the "$I" command in order to ensure the baseline functions of the RC car still work.
    - related lines of code will re-added in later updates and fixes
    [arduino_main.ino, servo_test.ino]
2026-05-24 Different, working version of previous code
    removed imu code, now allows for motor and servo control through commands
2026-06-14 Re-organized constant variables and command functions in rasp.py: - Adjustments to thresholds and ROIs - addition of clamp(), send_servo(), send_motor() functions - simplified motor commands - code c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
2026-06-14 Comment out debug print statements
    Comment out servo and motor value prints, and IMU initialization messages.
2026-07-12 Included function to detect orange and blue lines on the track in order to assist with counting turns.
2026-07-13 Added debugging lights to Raspberry Pi and Arduino code: 1. Red light turns on when in "FOLLOW_WALL" mode 2. Green light turns on when in "TURNING" mode
    Simplified Arduino code to use simpler gyroscope calculations for the IMU
2026-07-16 Added IMU command (I) for Raspberry Pi and additional requirements to complete a turn.
2026-07-18 Minor hotfix to use instances of the $I command in the Raspberry Pi's python code
2026-07-18 Accomodation for the newly implemented IMU functions in the main loop of the Arduino code
2026-07-20 Updated buffer for running the main python code to wait for the Arduino to complete IMU calibration.
2026-08-02 Updates to the state machine and starting sequence: - Adjusted starting sequence to gaurantee the bot starts upon running the code. The main program now starts only once the Arduino finishes calibrat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
2026-08-08 Creation of pillar detection system: - Defined ROI to detect pillars - Largest detected pillar in the ROI is treated as part of the corresponding wall and given extra weight when calculating steering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
2026-08-09 Major changes to arduino_main.ino and rasp.py:
    ----------------------------------------
    rasp.py:
    - Rudimentary additions to "TURNING" mode:
    -Addition of an ENTER_TURN_THRESH_UPPER to allow turns when the rc car is too close to the back wall
    - Splits detect_colored_line() function to individually detect blue and orange lines
    - Aimed at informing turning decisions in case of the triggering of ENTER_TURN_THRESH_UPPER
    arduino_main.ino:
    - De-bloated sketch (removed functions related to the magnometer and quarternation features)
    -Aimed at reducing start-up time
    [arduino_main.ino]
2026-08-23 Update arduino_main.ino
    Changed into a simplified version
2026-09-03 Updated Raspberry Pi code startup to match Arduino code
2026-09-04 Altered stopping requirements for the robot (Open Challenge): - Robot no longer relies on counting coloured lines on the map (lines 327-332 removed) - The above solution caused issues with consistent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
    - Robot now counts completed turns using the IMU
    - After 11 counted turns, robot begins stopping procedure, which is programmed to last ~2 seconds
    - Solution is now detattatched from the external environment and is based on the car's internal orientation, proving to be more reliably consistent
    [arduino_main.ino]
2026-09-04 Update README.md
    Added some information on Power and Sensor Architecture
2026-09-05 Large changes to Raspberry Pi: ---------------------------------------- 1. Addition of `raspConfig.py`: - All raspberry constants and most variables are now defined in a configuration file - All pyth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
    2. Alterations to IMU code:
    - IMU reading is completely decoupled from the state machine to provide more accurate headings when needed
    - Fixed improper stopping time by making sure `stopTime` can only be set once
    - Stopping requirements increased by 1 turn
    [raspConfig.py]
2026-09-05 Moved arduino into Code fiolder
2026-09-05 Fixed up Code folder organization
    [arduino_main.ino, bldc_test.ino, servo_test.ino]
2026-09-05 Moved arduino code into code
2026-09-05 Update README.md
    correct spelling of chassis
